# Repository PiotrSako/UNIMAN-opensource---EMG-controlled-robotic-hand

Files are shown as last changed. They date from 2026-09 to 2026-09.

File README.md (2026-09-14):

# UNIMAN — EMG-controlled robotic hand

An open, 3D-printable robotic hand controlled by a surface EMG sensor.
Contract your forearm muscle and the printed hand closes.

It is an educational platform, not a prosthesis and not a medical
device — built to make the path from a muscle signal to a moving hand
something you can build yourself and understand at every step.



## What it does

- Seven printed parts, fingers come off the printer already articulated
- One servo drives all five fingers through tendon cables
- Calibrates itself to whoever is wearing the electrode, in about
  thirty seconds
- Two control modes: hold to close, or toggle on each contraction

## How the control works

The sensor outputs a signal envelope proportional to muscle effort.
The firmware compares it against two thresholds — above the upper one
the hand closes, below the lower one it opens, and in between the state
is held. That gap is what keeps the hand from oscillating near the
switching point.

Both thresholds come from calibration rather than from constants,
because signal amplitude varies by a factor of two or three between
people.

## Repository layout

| Folder | Contents |
|---|---|
| `hardware/` | STL files for 3D printing |
| `firmware/` | Arduino sketch |
| `electronics/` | Wiring diagram |

## Limitations

Binary control, no force feedback, a single EMG channel, and testing on
a small number of people.

## Licence

See [LICENSE](LICENSE).

## Author

Piotr Sakowski

UNIMAN was presented as *True Motion: From muscle signal to robotic
hand motion*.

Email: piotrsakowski333@gmail.com  
LinkedIn: https://www.linkedin.com/in/sako-piotr/

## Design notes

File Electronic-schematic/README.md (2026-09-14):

# Electronics

Wiring diagram for UNIMAN.

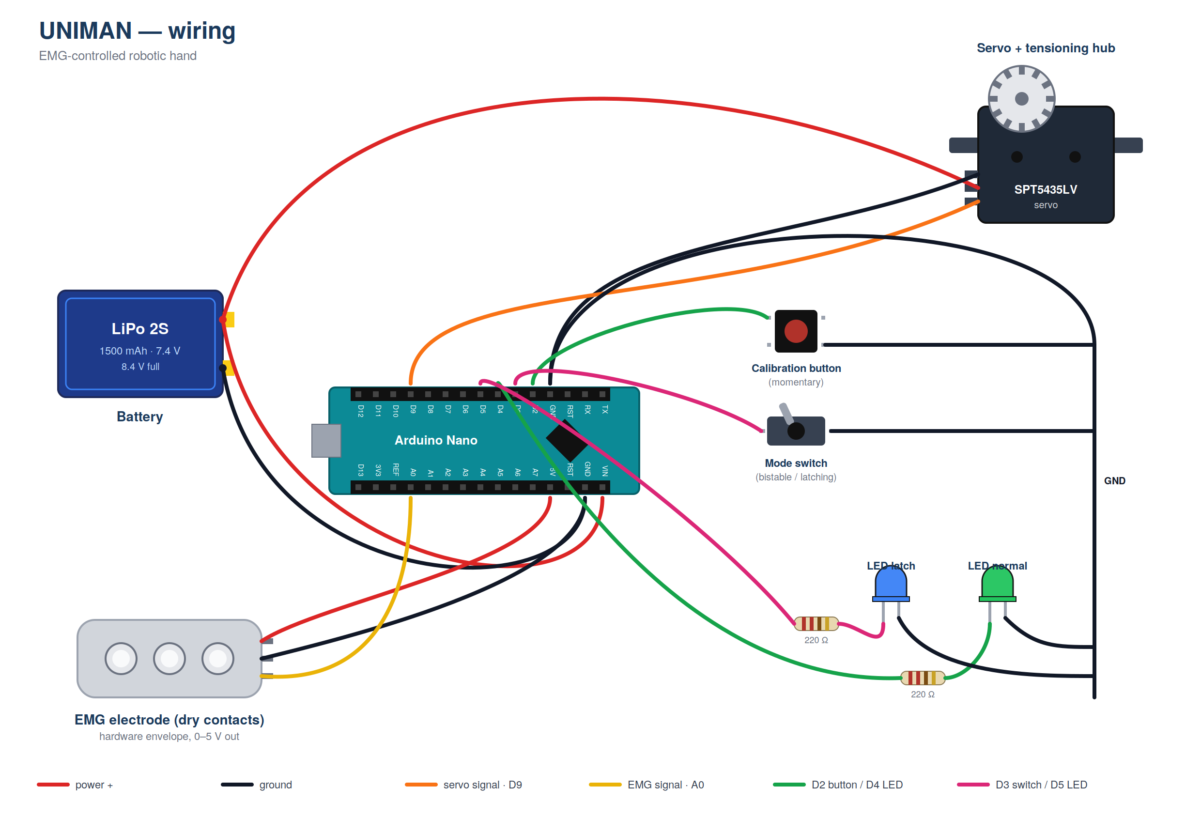
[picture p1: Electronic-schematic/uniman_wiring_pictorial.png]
UNIMAN wiring diagram


Pin assignment:

| Pin | Function |
|---|---|
| A0 | EMG envelope input |
| D2 | Calibration button (momentary, to GND) |
| D3 | Mode switch (bistable, to GND) |
| D4 | LED — normal mode |
| D5 | LED — latch mode |
| D9 | Servo signal |

The servo is powered directly from the 2S LiPo. The EMG electrode and
LEDs are powered from the Nano's 5 V rail.

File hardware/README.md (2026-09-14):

# Hardware

STL files for 3D printing. Housing, cover and five
print-in-place fingers.

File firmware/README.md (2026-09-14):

This is the source code for arduino nano.

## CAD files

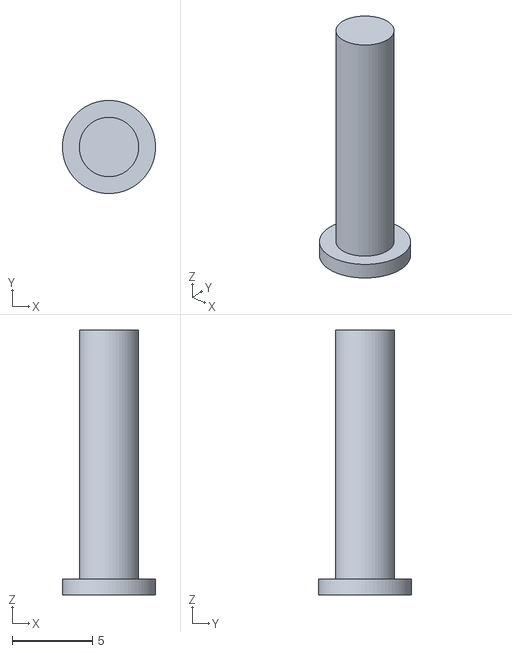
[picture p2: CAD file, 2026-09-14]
hardware/thumb locking pin.stl
5.80 x 5.80 x 16.5

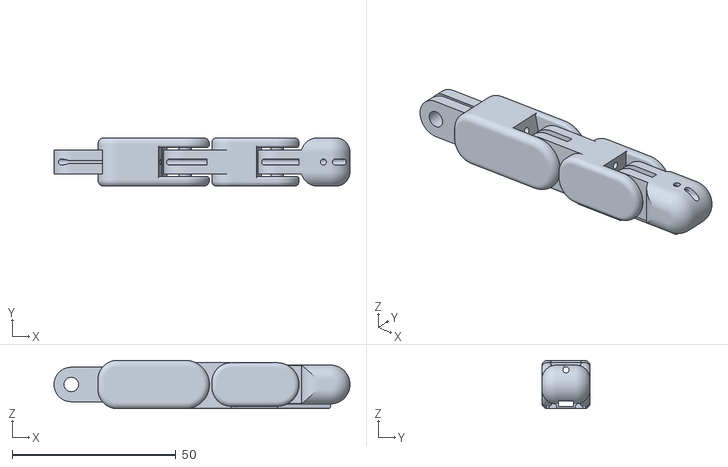
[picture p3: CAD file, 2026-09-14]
hardware/Ring.stl
90.4 x 14.8 x 14.8

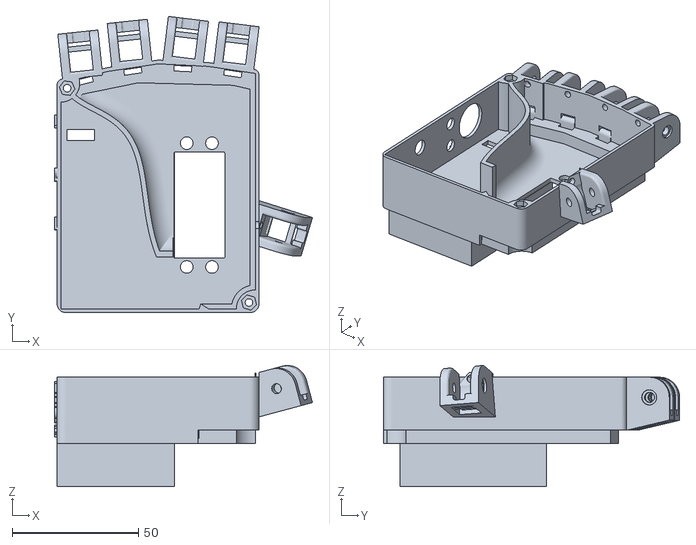
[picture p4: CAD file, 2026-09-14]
hardware/BASE.stl
102.2 x 117.3 x 47.9

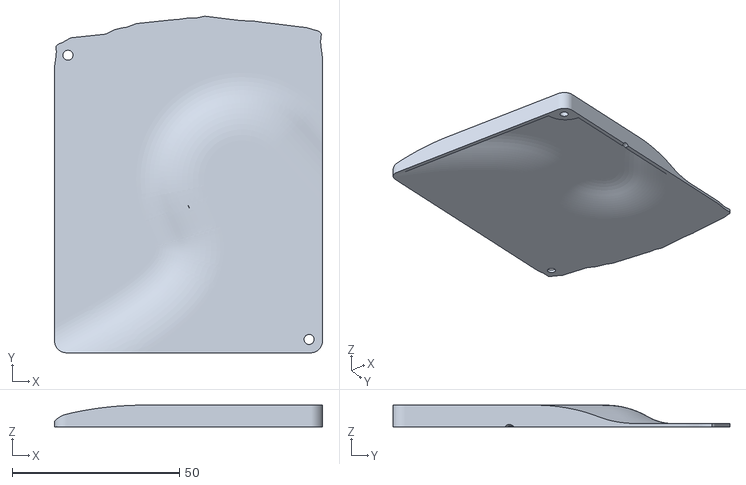
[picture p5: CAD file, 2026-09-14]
hardware/Base cover.stl
80.0 x 100.5 x 6.50

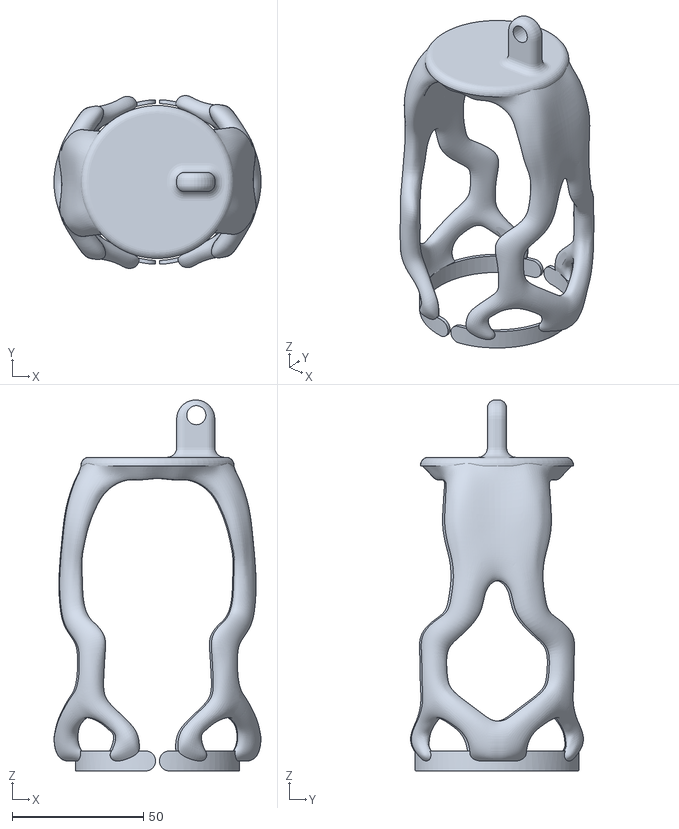
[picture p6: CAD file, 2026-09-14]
hardware/Universal hand mount.stl
79.0 x 66.0 x 141.6

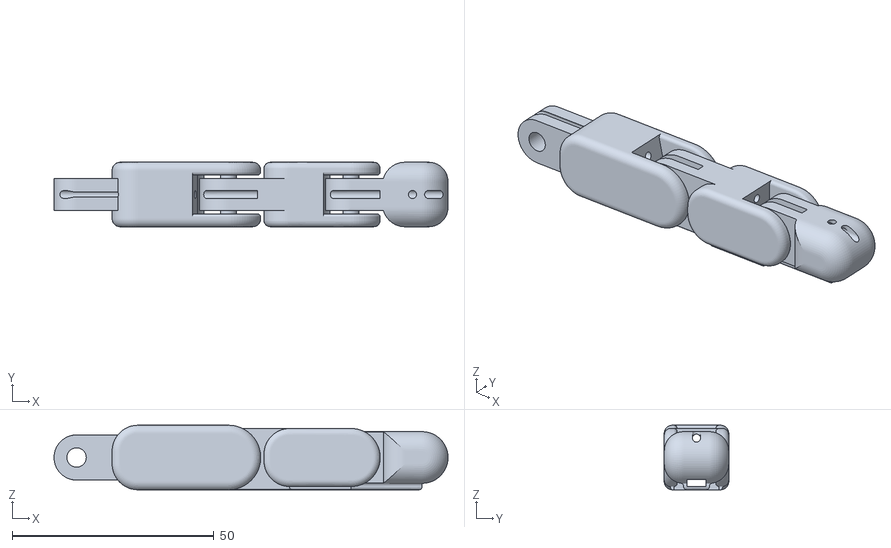
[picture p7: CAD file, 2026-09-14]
hardware/Middle.stl
97.6 x 16.0 x 16.0

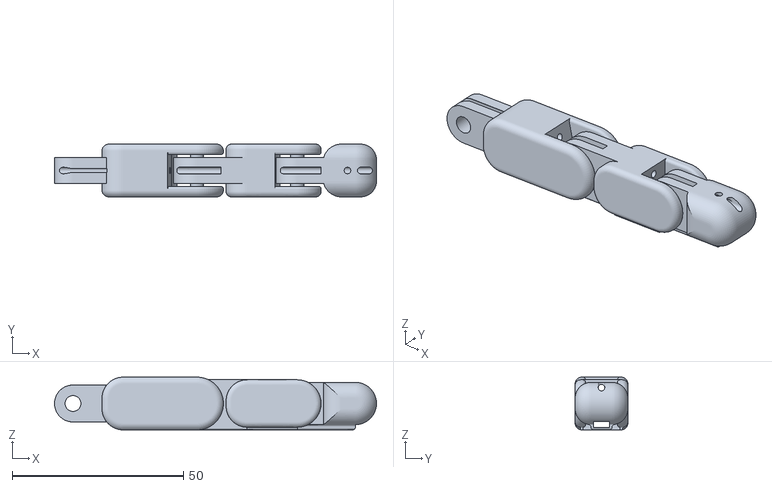
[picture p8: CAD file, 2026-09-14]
hardware/Pointer.stl
93.9 x 15.4 x 15.4

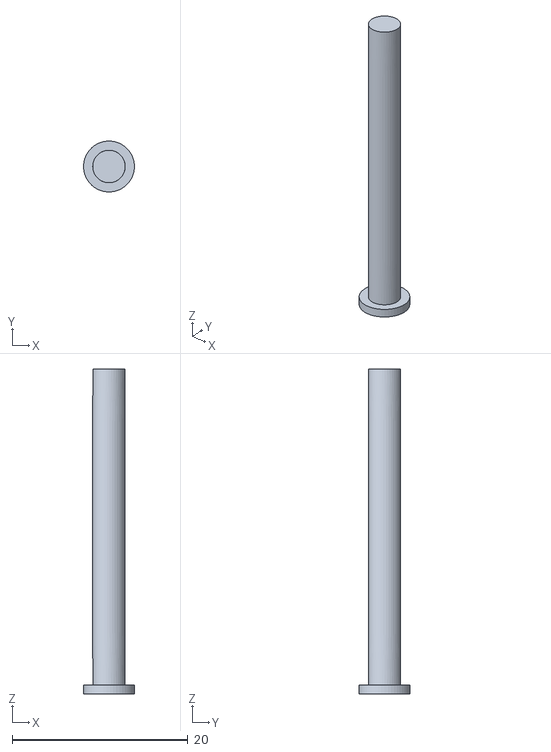
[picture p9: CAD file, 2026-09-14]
hardware/finger double locking pin.stl
5.79 x 5.80 x 37.0

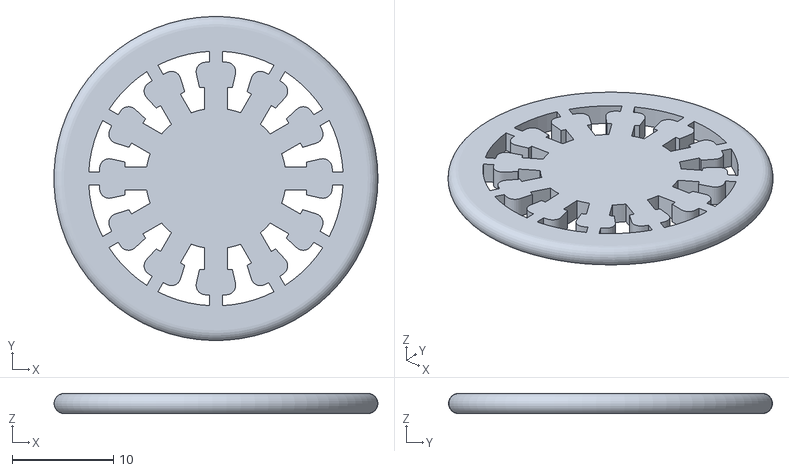
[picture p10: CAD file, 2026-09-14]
hardware/Tensioning Hub cover(print with tpu).stl
32.0 x 32.0 x 2.00

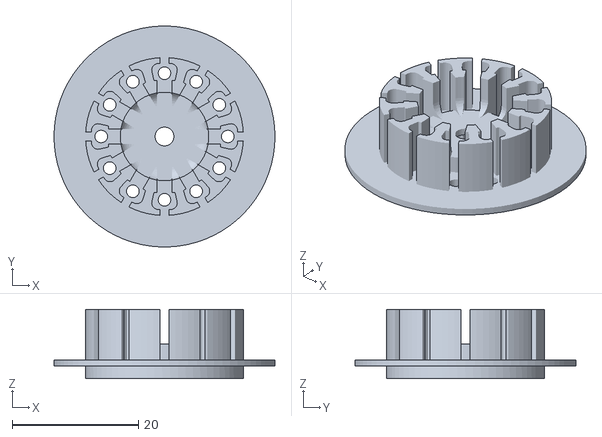
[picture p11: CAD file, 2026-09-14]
hardware/Radial tensioning hub.stl
35.0 x 35.0 x 11.0

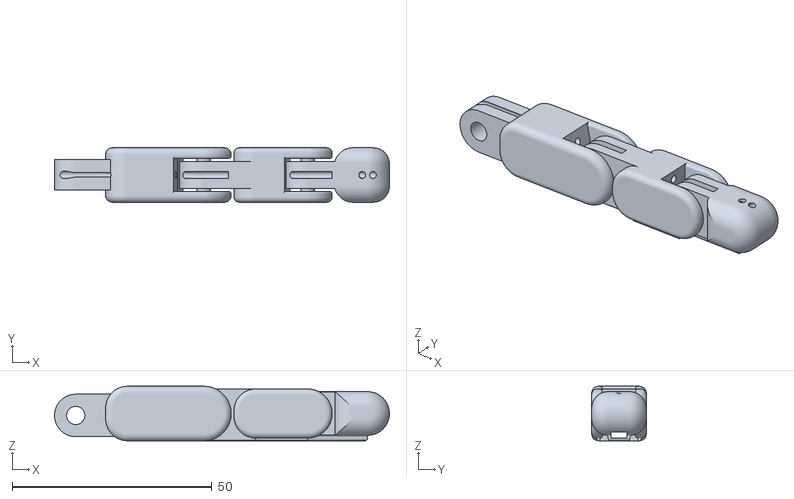
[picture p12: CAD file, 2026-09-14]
hardware/Pinky.stl
83.9 x 13.7 x 13.7

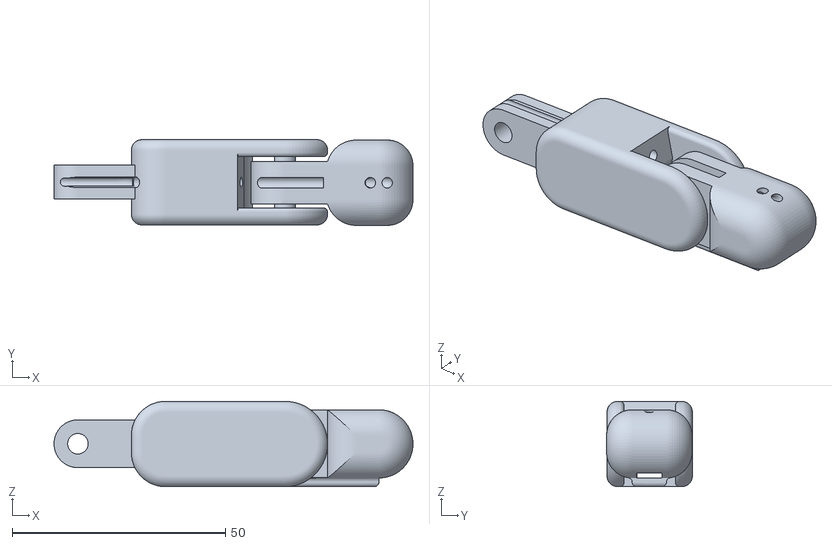
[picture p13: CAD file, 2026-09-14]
hardware/Thumb.stl
84.1 x 20.1 x 20.0

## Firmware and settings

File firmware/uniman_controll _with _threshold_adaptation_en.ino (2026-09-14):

#include <Servo.h>

const int EMG_PIN       = A0;
const int BUTTON_PIN    = 2;   // calibration button
const int MODE_PIN      = 3;   // mode switch
const int LED_NORMAL    = 4;   // normal mode LED
const int LED_LATCH     = 5;   // latch mode LED
const int SAMPLES       = 8;

const int SERVO_OPEN    = 500;
const int SERVO_CLOSE   = 2500;

int THRESHOLD_ON  = 450;
int THRESHOLD_OFF = 350;

Servo myServo;
bool active = false;
bool prevContraction = false;   // for edge detection in latch mode
bool prevMode = false;          // for mode change detection

int readEMGAveraged() {
  long sum = 0;
  for (int i = 0; i < SAMPLES; i++) {
    sum += analogRead(EMG_PIN);
  }
  return sum / SAMPLES;
}

int median(int *arr, int n) {
  for (int i = 0; i < n - 1; i++) {
    for (int j = 0; j < n - i - 1; j++) {
      if (arr[j] > arr[j + 1]) {
        int tmp = arr[j];
        arr[j] = arr[j + 1];
        arr[j + 1] = tmp;
      }
    }
  }
  return arr[n / 2];
}

void calibration() {
  Serial.println("=== ADAPTIVE CALIBRATION ===");
  delay(1500);

  // --- PHASE 1: REST (10 sec) ---
  Serial.println(">>> RELAX THE MUSCLE FOR 10 SECONDS <<<");
  Serial.println("Just hold your arm loose...");
  delay(2000);
  Serial.println("Measurement START");

  const int N_REST = 400;
  int restSamples[N_REST];
  int maxRest = 0;
  for (int i = 0; i < N_REST; i++) {
    restSamples[i] = readEMGAveraged();
    if (restSamples[i] > maxRest) maxRest = restSamples[i];
    delay(25);
  }
  int medRest = median(restSamples, N_REST);
  THRESHOLD_OFF = medRest + 100;
  
  Serial.print("Rest median: ");
  Serial.println(medRest);
  Serial.print("Rest max: ");
  Serial.println(maxRest);
  Serial.print("THRESHOLD_OFF = ");
  Serial.println(THRESHOLD_OFF);

  delay(2000);

  // --- PHASE 2: CONTRACTIONS (15 sec) ---
  Serial.println(">>> PERFORM 3-5 STRONG CONTRACTIONS AT ANY PACE <<<");
  Serial.println("You have 15 seconds. Clench and relax.");
  delay(2000);
  Serial.println("Measurement START");

  int peakThreshold = maxRest + 50;
  
  const int N_FLEX = 600;
  const int MIN_PEAK_DIST = 40;
  const int MAX_PEAKS = 10;
  int peaks[MAX_PEAKS];
  int peakCount = 0;
  
  int currentPeak = 0;
  int samplesSinceLast = MIN_PEAK_DIST;
  bool inContraction = false;
  
  for (int i = 0; i < N_FLEX; i++) {
    int sample = readEMGAveraged();
    samplesSinceLast++;
    
    if (sample > peakThreshold && !inContraction && samplesSinceLast >= MIN_PEAK_DIST) {
      inContraction = true;
      currentPeak = sample;
    }
    
    if (inContraction) {
      if (sample > currentPeak) currentPeak = sample;
      
      if (sample < peakThreshold - 30) {
        if (peakCount < MAX_PEAKS) {
          peaks[peakCount] = currentPeak;
          peakCount++;
          Serial.print("Peak #");
          Serial.print(peakCount);
          Serial.print(": ");
          Serial.println(currentPeak);
        }
        inContraction = false;
        samplesSinceLast = 0;
      }
    }
    
    delay(25);
  }

  if (inContraction && peakCount < MAX_PEAKS) {
    peaks[peakCount] = currentPeak;
    peakCount++;
    Serial.print("Peak #");
    Serial.print(peakCount);
    Serial.print(": ");
    Serial.println(currentPeak);
  }

  if (peakCount < 2) {
    Serial.println("WARNING: Fewer than 2 contractions detected! Calibration failed.");
    return;
  }

  long peakSum = 0;
  for (int i = 0; i < peakCount; i++) {
    peakSum += peaks[i];
  }
  int peakAverage = peakSum / peakCount;
  THRESHOLD_ON = (peakAverage * 80L) / 100;

  Serial.print("Contractions detected: ");
  Serial.println(peakCount);
  Serial.print("Peak average: ");
  Serial.println(peakAverage);
  Serial.print("THRESHOLD_ON (80% of average) = ");
  Serial.println(THRESHOLD_ON);

  if (THRESHOLD_ON <= THRESHOLD_OFF) {
    Serial.println("WARNING: thresholds overlap! Repeat the calibration.");
  } else {
    int margin = THRESHOLD_ON - THRESHOLD_OFF;
    Serial.print("Margin between thresholds: ");
    Serial.println(margin);
  }

  Serial.println("=== CALIBRATION COMPLETE ===");
  delay(1000);
}

void setup() {
  Serial.begin(9600);
  pinMode(BUTTON_PIN, INPUT_PULLUP);
  pinMode(MODE_PIN, INPUT_PULLUP);
  pinMode(LED_NORMAL, OUTPUT);
  pinMode(LED_LATCH, OUTPUT);
  
  myServo.attach(9, SERVO_OPEN, SERVO_CLOSE);
  myServo.writeMicroseconds(SERVO_OPEN);
  
  // mode state initialization
  prevMode = (digitalRead(MODE_PIN) == LOW);
}

void loop() {
  // --- calibration button ---
  if (digitalRead(BUTTON_PIN) == LOW) {
    delay(50);
    if (digitalRead(BUTTON_PIN) == LOW) {
      calibration();
    }
  }

  // --- mode read (LOW = switch closed = LATCH mode) ---
  bool latchMode = (digitalRead(MODE_PIN) == LOW);
  
  // mode change detection -> reset to open position
  if (latchMode != prevMode) {
    active = false;
    prevContraction = false;
    myServo.writeMicroseconds(SERVO_OPEN);
    Serial.print(">>> MODE CHANGE: ");
    Serial.println(latchMode ? "LATCH" : "NORMAL");
    prevMode = latchMode;
    delay(100);  // short pause after the change
  }
  
  // --- LED indication ---
  digitalWrite(LED_NORMAL, latchMode ? LOW : HIGH);
  digitalWrite(LED_LATCH,  latchMode ? HIGH : LOW);

  // --- EMG read ---
  int emgRaw = readEMGAveraged();
  
  // contraction detection with hysteresis (common to both modes)
  bool contraction = prevContraction;
  if (emgRaw > THRESHOLD_ON)  contraction = true;
  if (emgRaw < THRESHOLD_OFF) contraction = false;

  // --- mode logic ---
  if (latchMode) {
    // LATCH MODE: rising edge toggles the state
    if (contraction && !prevContraction) {
      active = !active;
    }
  } else {
    // NORMAL MODE: state = current contraction
    active = contraction;
  }
  prevContraction = contraction;

  myServo.writeMicroseconds(active ? SERVO_CLOSE : SERVO_OPEN);

  Serial.print(emgRaw);
  Serial.print(",");
  Serial.print(THRESHOLD_ON);
  Serial.print(",");
  Serial.print(THRESHOLD_OFF);
  Serial.print(",");
  Serial.println(latchMode ? "LATCH" : "NORMAL");
  delay(20);
}

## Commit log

2026-09-14 Add README for hardware with STL file details
2026-09-14 Add README for Arduino Nano source code
2026-09-14 Add README with description of wiring diagram
